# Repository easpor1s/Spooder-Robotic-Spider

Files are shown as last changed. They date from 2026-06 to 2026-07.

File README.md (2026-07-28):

Spooder Zine (1)

## What is Spooder?
The first iteration of Spooder is a remote controlled robotic spider companion with 6 legs. It has a led display that projects a face and facial expressions based on the actions it takes. 
At its core, the robot is powered by a 2gb Raspberry Pi 4 connected to a Pimoroni Yukon developement board through UART. The legs use a three jointed, two axis design which allows for a high degree of movement.
On the legs, one servo controls the legs movement along the X axis and two along the Z axis. This design is very similar to the joint of your finger and allows the robot to grab at objects and sweep itself along smoothly.



## How do I interact with Spooder?
The first iteration of Spider will be controlled via a game console controller such as an Xbox gamepad. The left joystick will control the robots front and back movement, while the right joystick will control the robots left and right movement. The controller will be 
connected to the robot via a 2.4ghz dongle, which keeps hardware requirements simple and reduces our costs. Using a controller with a dongle also eliminates Bluetooth pairing problems, which can be frustrating to troubleshoot. 
Additional functions will be mapped to the controller's shoulder buttons, directional pad, and the ABYX buttons as they are developed. The controller we are using is a 8BitDo Ultimate 2C game pad which has good buld quality and is very affordable. Spooder requires python 3.9 or newer, PIGPIO for controlling servos, and pygame. 

## Why does it exist?
Both of us are in the same robotics competition and wanted to try something new. We only built wheeled drivetrains for our Vex bots and any variation in design is still centered around wheels but just in different configurations. 
We decided to try something new, so we settled on a walker robot idea that relies on legs with servos instead of wheels with motors. Additionally, with our previous robots, the building and design experience was highly procedural where all the parts came from a standardized catalogue which made the experience feel repetitive. 
This project is our attempt at widening our hardware knowledge base and learning new skills while yielding something meaningful. Both of us have little to no experience with the components and steps we are using in the making of Spooder which is a steep learning curve and why this project is being attempted. 

## What are the future plans of Spooder?
In the future, we aim to have Spooder have the hardware to run a local large language model and be able to track and follow you without human input. 
We also aim for Spooder to be able to react to gestures such as waves, thumbs up, and maybe even give high-fives where it will raise on of its legs to tap your hand. In the future, components that will allow the bot to jump up onto or over obstacles may be added through spring or pneumatic systems as well. 

## Instructions
Because the models and enclosure is split into multiple components, assembly can be quite tricky.
- 3d print all models with petg or CF-petg except for the leg tips, which should use TPU.
- Add appropriate brass inserts and bearings, which should be heat set and friction fit appropriately
- Sand down joints if needed
- Assemble left and right legs, and mount the body servo arm to the top part of the legs
- Attach the motors to the mounts on the body, and then attach the leg assembly to them.
- Add electronics to the baseplate, and the LED matrix to the top enclosure
- Wire all components and add power supply and power bank
- Assemble all components together, the leg mounts, guards and top enclosure to the baseplate
## Setting up code
To set up code, first make sure all hardware dependencies are met. You will need a Pimoroni Yukon with 5 servo modules attached, a USB-A to USB-C cable running from the Raspberry Pi to the Yukon, a gamepad dongle plugged into the pi and your gyro connected to the pi through i2c as well. On the software side, you must have Python 3.9 and the Pigpio system on the Pi. 

PowerShell:

powershell 
```sh
-ExecutionPolicy Bypass -File .\deploy.ps1 -PiHost "your_pi_ip" -PiUser "your username"
```
Raspi Terminal:

Setup Environment:
```sh
ssh your_username@your_pi_ip_here cd /home/your_username/hexapod chmod +x setup_pi.sh ./setup_pi.sh 
```
Install sys dependancies:
```sh
sudo apt-get update
sudo apt-get install python3 python3-pip python3-venv pigpio python3-pigpio git -y
sudo systemctl enable --now pigpiod
```
Install Libraries:
```sh
cd /home/your_username/hexapod source venv/bin/activate pip install --upgrade pip setuptools wheel pip install pygame pyyaml pip install --no-cache-dir adafruit-circuitpython-lsm6ds 
```
Run controller: 
```sh
sudo /home/your_username/hexapod/venv/bin/python3 /home/spooder/hexapod/main.py 
```

## Built With
[PIGPIO](https://github.com/joan2937/pigpio) for servo control

[pygame](https://github.com/pygame/pygame)

## Programs
[Autodesk Fusion](https://www.autodesk.com/uk/products/fusion-360/overview) for CAD design

[Canva](https://www.canva.com/) for graphic design

[CirkitDesigner](https://app.cirkitdesigner.com/project/475be11a-6594-4d5f-bd77-2635c9dc39ba) circuit diagram

[Desmos](https://www.desmos.com/) movement calculations

[Visual Studio Code](https://code.visualstudio.com) Code and SSH access

## License
Distributed under the MIT License. See [MIT License](https://opensource.org/licenses/MIT) for more information.

## Circuit diagram
Spooder Wiring

## Inverse Kinematics Calculations
2d https://www.desmos.com/calculator/ezvpfhsskw
3d https://www.desmos.com/3d/tjnpyzfqji





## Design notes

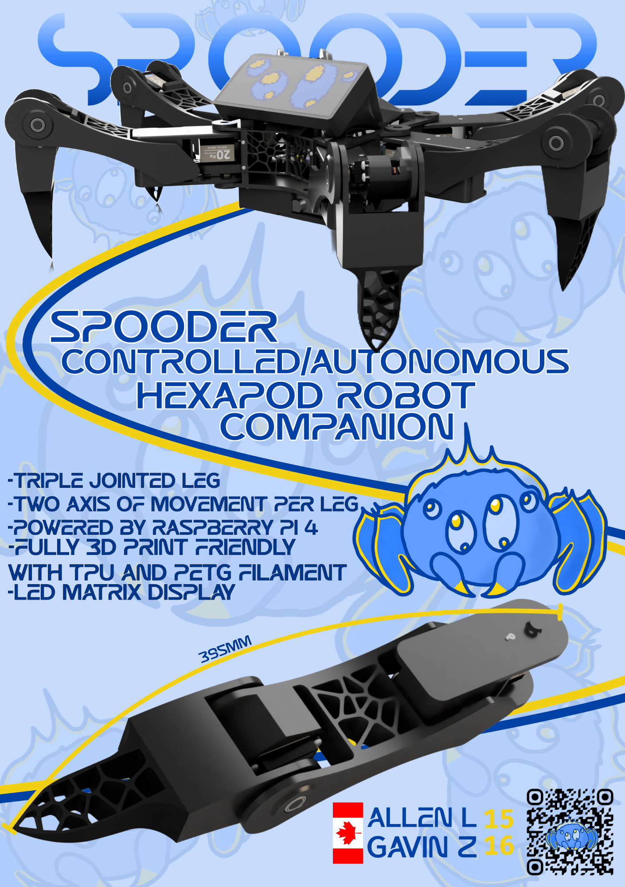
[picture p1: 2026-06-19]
Spooder Zine.png

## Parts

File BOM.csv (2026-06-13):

Component | Description | Quantity | Unit Cost in CAD | Total Cost in CAD | Source | Ownership
Pimoroni Yukon | Servo control board | 1x | $37.32 | $37.32 | https://shop.pimoroni.com/products/yukon?variant=41185258111059
Gyro & Accel | Gyro for stability | 1x | $19.11 | $19.11 | https://shop.pimoroni.com/products/adafruit-lsm6ds3tr-c-6-dof-accel-gyro-imu-stemma-qt-qwiic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
Servo Module | Adapter add servos to Yukon | 5x | $9.00 | $37.32 | https://shop.pimoroni.com/products/quad-servo-module-for-yukon?variant=41187321446483
Servo 4 pack | Servos | 4x | $65.00 | $259.96 | https://www.amazon.ca/HOOYIJ-Digital-Waterproof-DS3225-Steering/dp/B0D6RRGDLP
Servo 2 pack | Servos | 1x | $43.98 | $43.98 | https://www.amazon.ca/dp/B08DCHGRXG?ref=ppx_yo2ov_dt_b_fed_asin_title
T to XT30 adpt | Adpt to onnect LIPo to Yukon | 1x | $9.99 | $9.99 | https://www.amazon.ca/LinsyRC-T-Plug-Connector-Adapter-Battery/dp/B0CZTNMJHF
2S LIPo 2 pack | Batteries to power servos | 1x | $34.64 | $34.64 | https://www.amazon.ca/GOLDBAT-5200mAh-Connector-Airplane-Helicopter/dp/B08CV8TLFT
STEMMA cable | Connect gyro to pi | 1x | $2.81 | $2.81 | https://shop.pimoroni.com/products/jst-sh-cable-qwiic-stemma-qt-compatible?variant=40409136332883
2.5 Scrw 50pc | Assembly Screws | 1x | $9.98 | $9.98 | https://www.amazon.ca/M2-5-0-45x10mm-Phillips-Machine-Stainless-Countersunk/dp/B0FB8XR995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
2.5 Scrw btn 565 pc | Assembly Screws | 1x | $16.53 | $16.53 | https://www.amazon.ca/dp/B075RCLBBH?ref=ppx_yo2ov_dt_b_fed_asin_title
Bearings 30pc | Bearings | 1x | $22.31 | $22.31 | https://www.amazon.ca/Fafeicy-10x15x4mm-Shielded-Precision-Applications/dp/B0GK24M3W8
Brass insert 100pc | Brass inserts for screws | 1x | $10.99 | $10.99 | https://www.amazon.ca/HANGLIFE-Heat-Set-Threaded-Printing-Components/dp/B0CS6YVJYD
TPU filiment | Filiment to print parts | 1x | $22.99 | $22.99 | amazon.ca/dp/B0BBM6R5VM?ref=ppx_yo2ov_dt_b_fed_asin_title
PETG filiment | Filiment to print parts | 1x | $32.99 | $32.99 | amazon.ca/dp/B0DFCF582M?ref=ppx_yo2ov_dt_b_fed_asin_title
Game Pad | Controller for Spooder | 1x | $33.29 | $33.29 | https://www.amazon.ca/8Bitdo-Ultimate-Controller-Joysticks-Remappable/dp/B0D72TNXSC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 | OWNED
Buck Convert | Adapt powerbank to Pi | 1x | $20.99 | $20.99 | https://www.amazon.ca/dp/B093VB61Y6?ref=ppx_yo2ov_dt_b_fed_asin_title
Raspberry Pi 4 | Controls Spooder | 1x | $100.23 | $100.23 | https://www.amazon.ca/Raspberry-Model-2019-Quad-Bluetooth/dp/B07TD42S27?sbo=RZvfv%2F%2FHxDF%2BO5021pAnSA%3D%3D | OWNED
Ugreen 67w | Power Raspi 4 | 1x | $57.84 | $57.84 | https://www.walmart.com/ip/ugreen-65W-20000mAh-Portable-Power-Pack-with-1-USB-C-cable-1-USB-C-port-1-USB-A-port/17498716367 | OWNED
USB-C adapt | Adpt powerbank to buck convert | 1x | $15.00 | $15.00 | https://www.amazon.ca/CERRXIAN-USB-5-5mm-2-1mm-Replacement/dp/B0DLKSWKN7
LED matrix | Display for Spooder | 1x | $39.15 | $39.15 | https://www.amazon.ca/Waveshare-Full-Color-Adjustable-Brightness-Compatible/dp/B0BQYDLHY9?s=electronics
8-32 inserts 50 pack | Threaded inserts for screws | 1x | $10.69 | $10.69 | https://www.amazon.ca/Threaded-American-Standard-Hardware-Components/dp/B0DS653YLX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
Matrix Bonnet | Connect screen to Raspi | 1x | $17.43 | $17.43 | https://shop.pimoroni.com/products/adafruit-triple-led-matrix-bonnet-for-raspberry-pi-for-hub75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
M3 screws | Assembly Screws | 1x | $13.59 | $13.59 | https://www.amazon.ca/M3-0-5-Button-Stainless-Machine-Threaded/dp/B0C6WLLV3H?sp_csd=d2lkZ2V0TmFtZT1zcF9hdGY
8-32 Screws 100 pack | Assembly Screws | 1x | $17.00 | $17.00 | https://www.amazon.ca/NIULUNBAO-Stainless-Machine-Threaded-Assortment/dp/B0DMV2WB4X?gad_source=1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
Total |  |  |  | $886.13
Total with Tax |  |  |  | $930.44

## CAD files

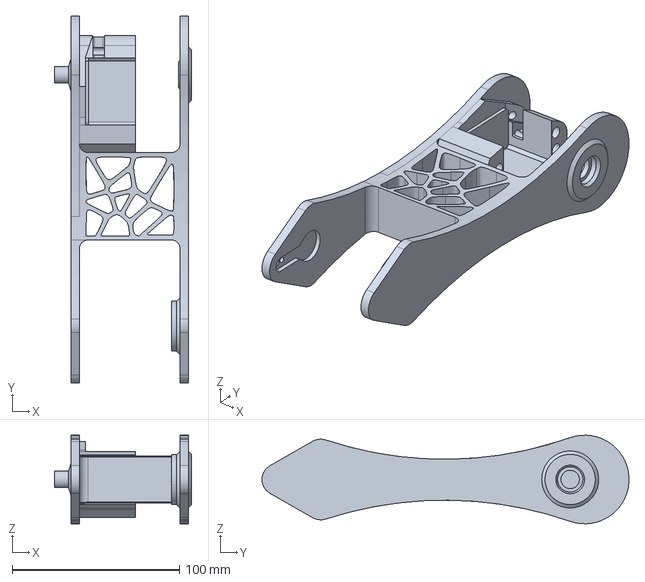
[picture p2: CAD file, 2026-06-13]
CAD/SpooderV1models/left_leg/left_mid.step
82.0 x 219.1 x 52.9 mm

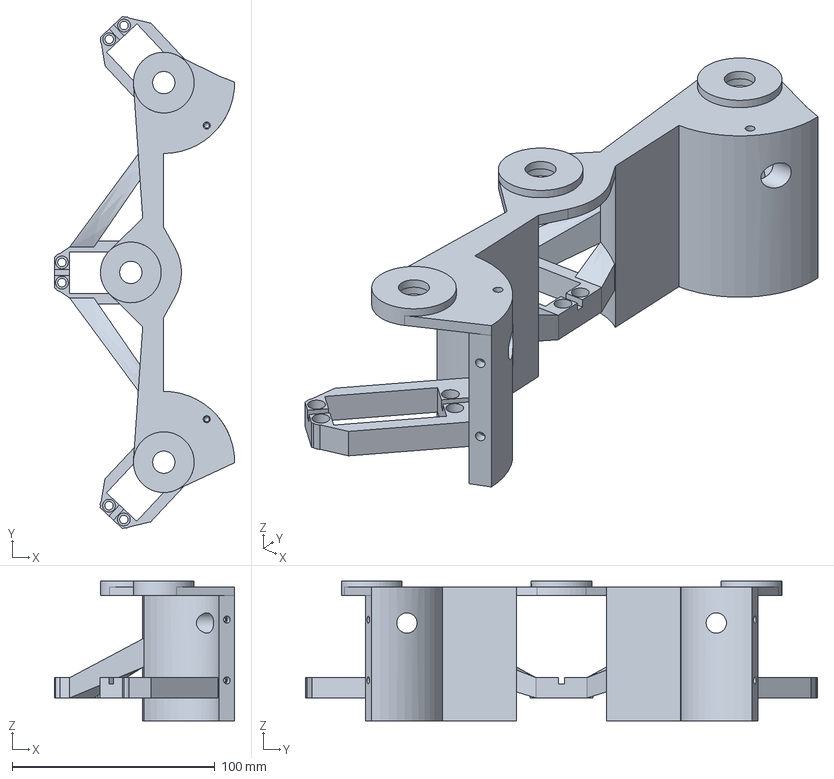
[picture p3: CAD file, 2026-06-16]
CAD/SpooderV1models/left_mount.step
89.0 x 252.8 x 69.0 mm

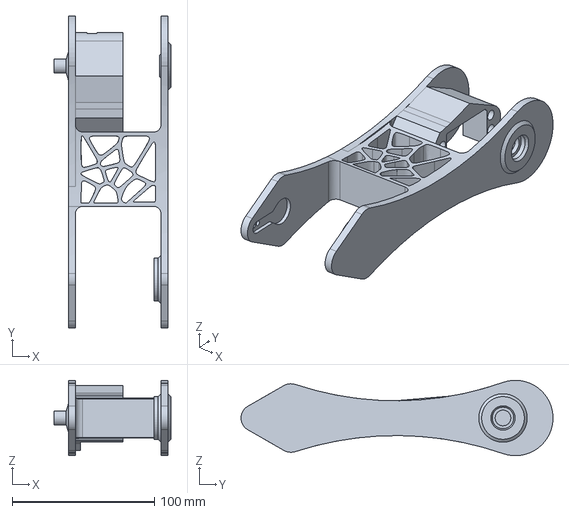
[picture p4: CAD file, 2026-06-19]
CAD/SpooderV1models/right_leg/right_mid.step
82.0 x 219.1 x 52.9 mm

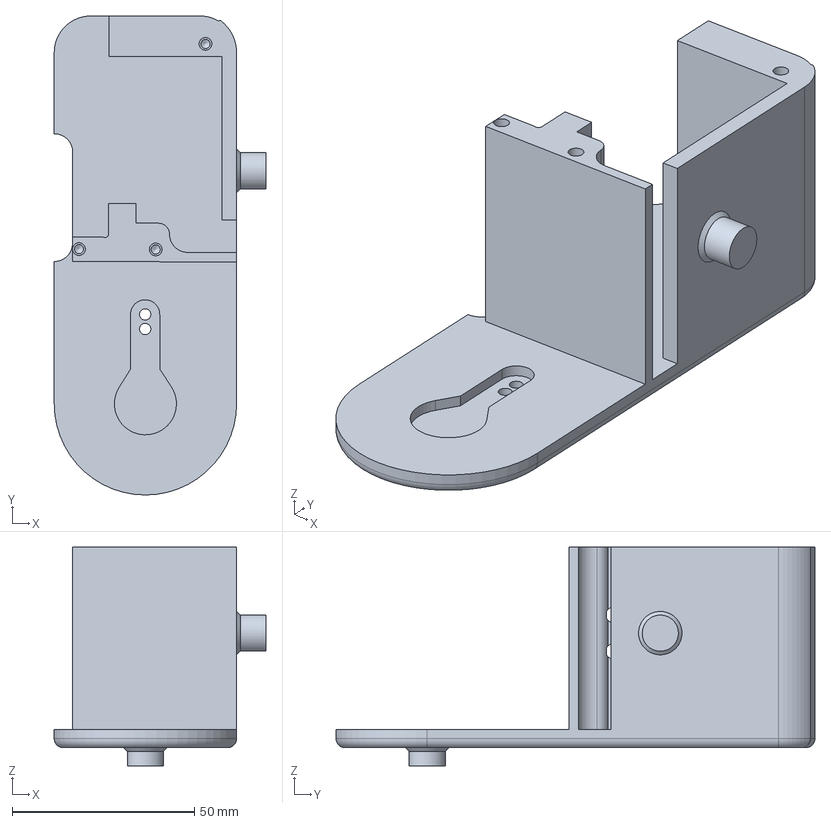
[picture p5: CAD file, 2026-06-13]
CAD/SpooderV1models/left_leg/left_upper_bottom.step
58.0 x 131.3 x 60.0 mm

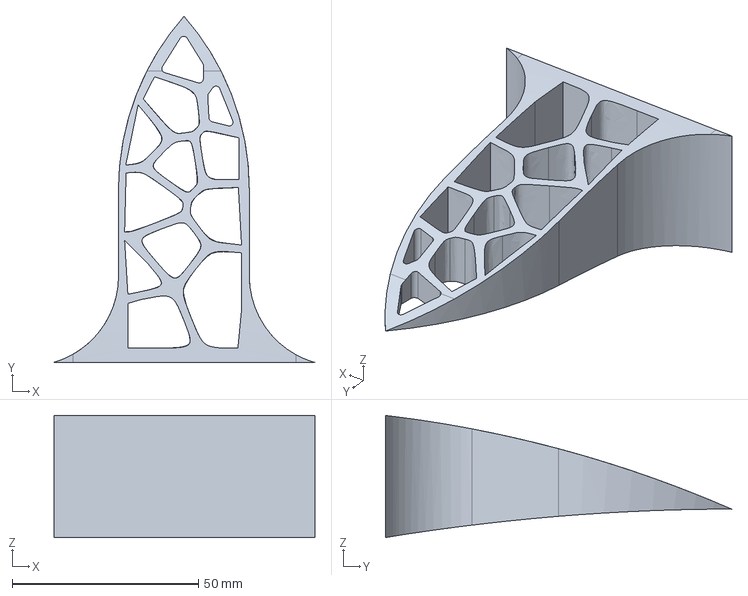
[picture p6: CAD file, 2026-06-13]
CAD/SpooderV1models/right_leg/right_claw_bottom.step
70.0 x 92.9 x 32.8 mm

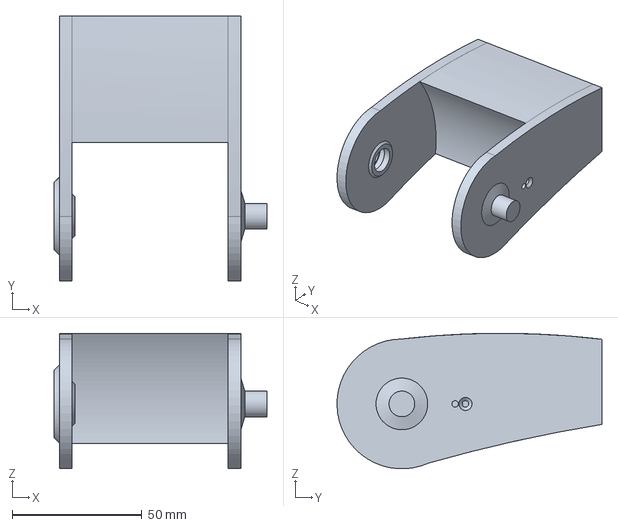
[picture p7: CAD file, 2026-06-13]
CAD/SpooderV1models/left_leg/left_claw_top.step
82.0 x 102.1 x 52.2 mm

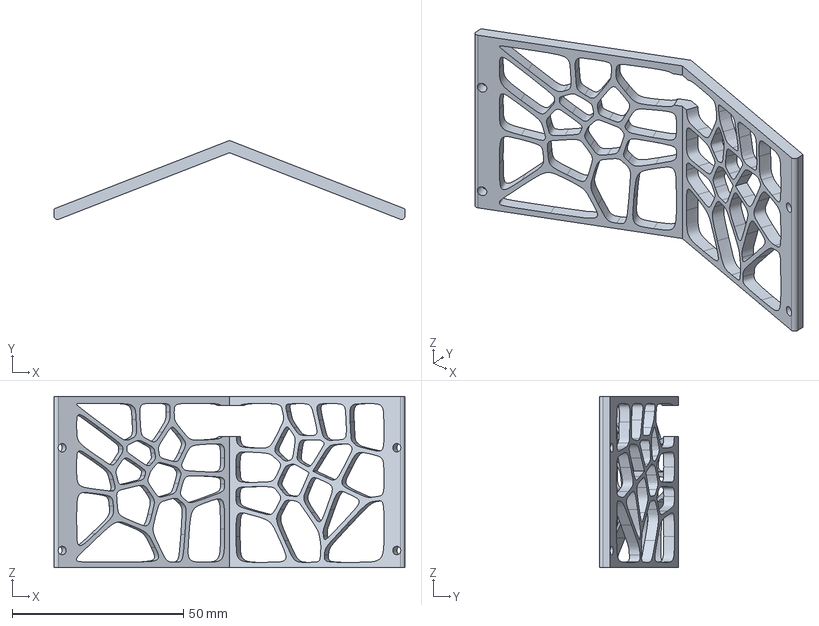
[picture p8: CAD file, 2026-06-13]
CAD/SpooderV1models/rearfront_guard.step
102.5 x 23.1 x 50.0 mm

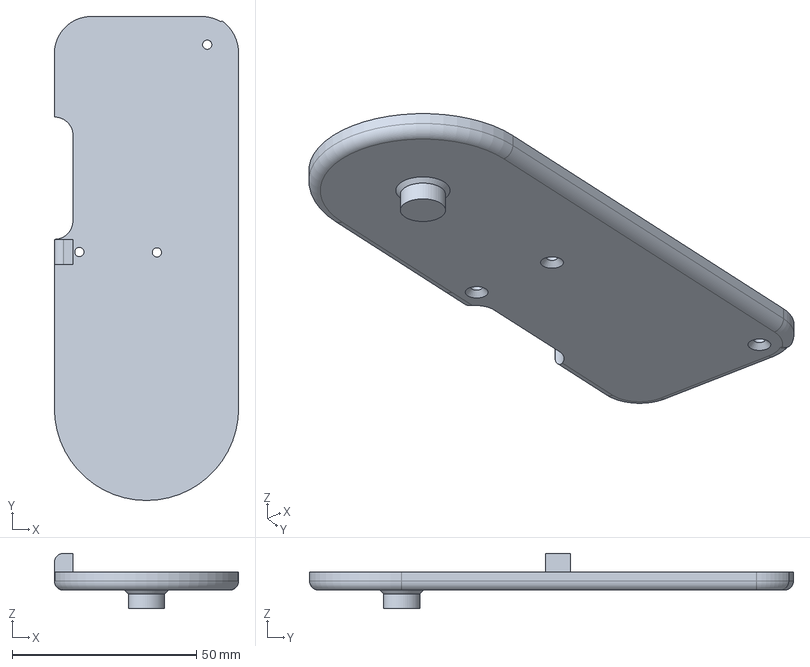
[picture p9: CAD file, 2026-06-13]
CAD/SpooderV1models/right_leg/right_upper_top.step
50.0 x 131.3 x 15.0 mm

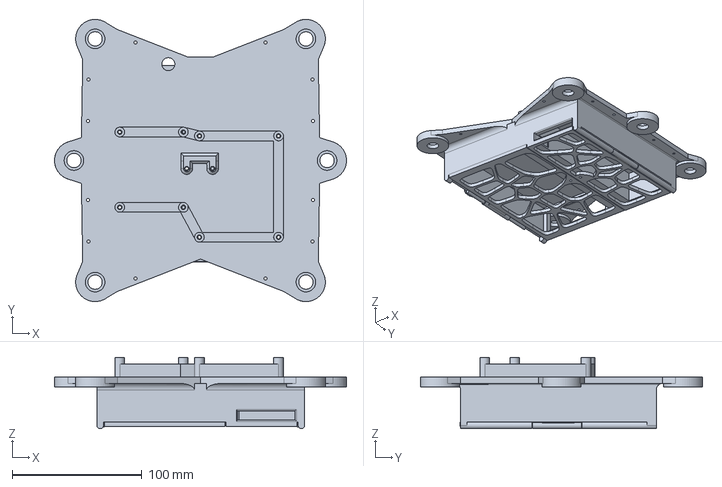
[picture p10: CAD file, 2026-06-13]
CAD/SpooderV1models/base_hinge.step
225.0 x 217.4 x 55.0 mm

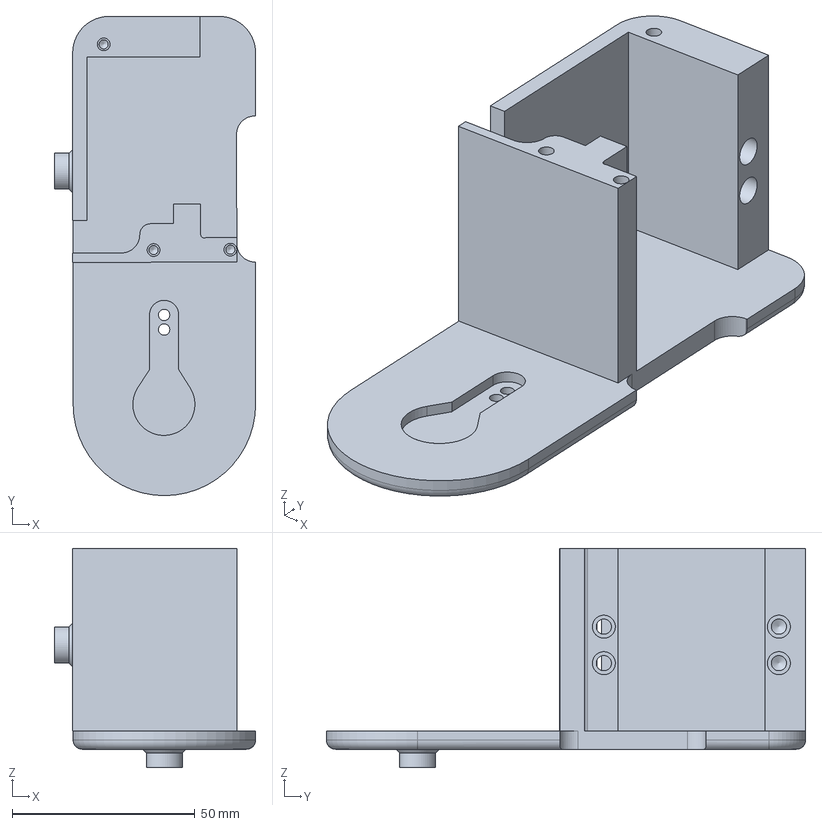
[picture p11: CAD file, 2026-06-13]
CAD/SpooderV1models/right_leg/right_upper_bottom.step
55.1 x 131.3 x 60.0 mm

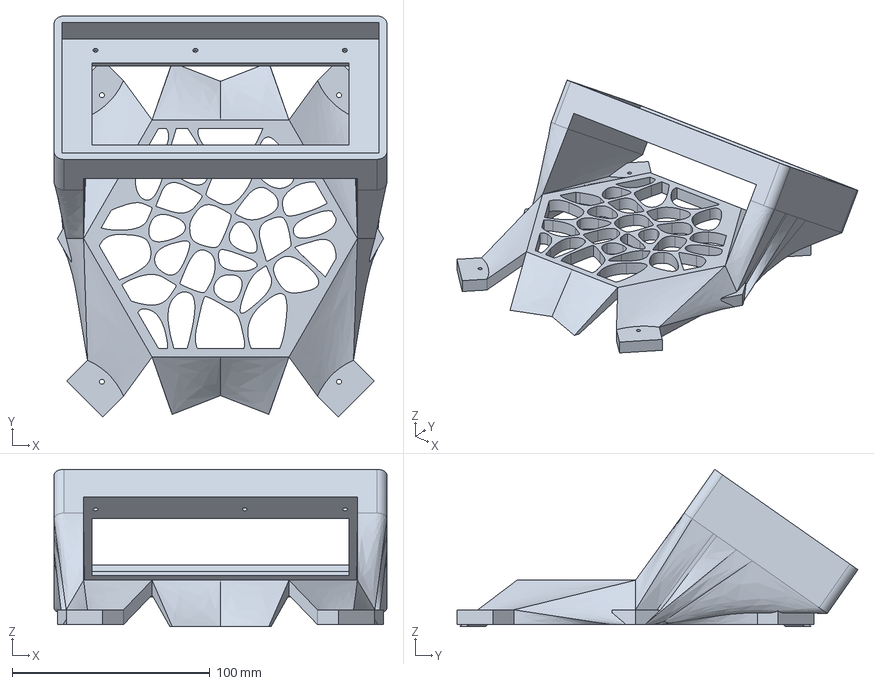
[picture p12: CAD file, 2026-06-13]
CAD/SpooderV1models/top_enclosure.step
168.5 x 202.9 x 79.6 mm

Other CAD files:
CAD/SpooderV1models/right_mount.step
CAD/SpooderV1models/left_leg/left_claw_bottom.step
CAD/SpooderV1models/left_leg/left_upper_top.step
CAD/SpooderV1models/right_leg/right_claw_top.step
CAD/left.f3z
CAD/right.f3z

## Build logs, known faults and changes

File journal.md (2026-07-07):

# Spooder — Journal Export

- Exported at: 2026-07-07T22:23:32Z
- Project ID: 4099
- Entries: 36

## Entry 1
- ID: 10595
- Author: allenlin0728
- Created At: 2026-05-31T05:44:50Z

### Content

I started by looking at an old prototype of one of the arms that i made a while back and kind of just taking in the design, but ended up deleting most of it. I started to research about herringbone gears, as we were going to 3d print some of them for our design, and pulleys/belt, which I was not very experienced with. From this I did a little bit of scouting of parts and created a very rough draft on FUSION of our arm, with the pulleys, herringbone gears and the servo motors. The belts/pulleys were the main focus, where I decided for a 300mm long GT2 9mm pulley/belt from my research.




### Recording Links

- https://www.youtube.com/watch?v=wEREaV_vIaY

## Entry 2
- ID: 10819
- Author: allenlin0728
- Created At: 2026-06-01T03:55:55Z

### Content

I started to polish my old design up, where i spent lots of time joining and creating different parts, like the pulleys/helical gears. But after discussing, Gavin and I decided to scrap the old design entirely after seeing some other designs of a similar robot, where we now decided to use 3 servos, and 6 legs to make the movement more refined smooth. This meant we had to scrap our old design, and create a new one. After learning the size of our servos, which was much lighter/smaller than expected, we decided on directly placing the servos onto the joints, with ball bearings for less friction. This now allows us to turn our legs individually, but requires much more servos.



### Recording Links

- https://www.youtube.com/watch?v=X4d5mncq7Mc
- https://www.youtube.com/watch?v=3uG8w2orfYI
- https://www.youtube.com/watch?v=HCluzsvRUsA

## Entry 3
- ID: 10820
- Author: deez.ducks.ca
- Created At: 2026-06-01T03:57:54Z

### Content

I researched and sorted all the electronic components and materials needed for the robot and added them to a spread sheet with individual and total costs. I created our Github and wrote the projects read me as well as uploading the cost and materials spread sheet onto it. I started the logo for the project zine and added it to the Github. Some other additional house keeping items have also been taken care of. I have also determined the basic work flow we are going to use to electronics such as which modules attach where, how is power stepped down and delivered etc. (started at 1:40 ended at 9:30, OBS wasnt working for a few hours and didnt realize)



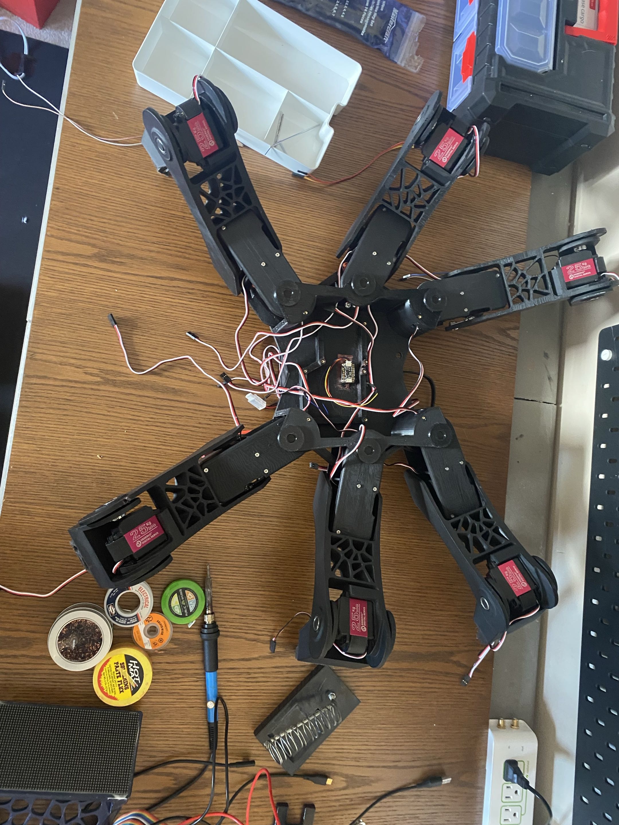
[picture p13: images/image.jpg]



### Recording Links

- https://www.youtube.com/watch?v=XxXYVmYsMW0
- https://www.youtube.com/watch?v=baPjPJVgMh8
- https://lookout.hackclub.com/api/media/7c6b96f3-029c-4d9d-af1d-7212b8e67b17/video.mp4

## Entry 4
- ID: 11060
- Author: deez.ducks.ca
- Created At: 2026-06-02T04:23:40Z

### Content

Polished GitHub, added milestone target and fixed some formatting issues. Researched and compiled electronics -> soldering iron, servos. Solved the major problem of how to power the Raspberry Pi 5 mobile on the robot at a reasonable cost. -> 67W Ugreen power bank with a USB-PD 2.0/3.0 to 5V 5A converter board. Researched and planned additional mounting hardware components to be used. Made a basic circuit diagram on how the electronics will be wired together. 


### Recording Links

- https://lookout.hackclub.com/api/media/a696c47c-5837-4988-a421-9487be0b5eb6/video.mp4

## Entry 5
- ID: 11065
- Author: allenlin0728
- Created At: 2026-06-02T04:42:57Z

### Content

I touched up the leg assembly by adding a pair of knobs as a axle fit for the ball bearings. 


After this I started on the main design, which would used 6 of these leg assemblies, but after moving some of the legs to the alternate side and flipping them around and rotating, I realized I had to mirror the other leg for a right side and a left side to have the motors oriented correctly. So I copied and edited one the leg assembly, flipping the top motor, which when rotated in the main assembly would allow for an alternate or mirrored leg. 


left side


right side

From this I positioned the legs temporarily at a even increment for simplicity.


One thing I noticed though is that the curve of the claw of the spider also needed to be mirrored, and possibly the central joint motors



I decided to do this tomorrow as it was getting that but this is to keep note of it.

### Recording Links

- https://www.youtube.com/watch?v=mTfh1b1T4Z4

## Entry 6
- ID: 11283
- Author: deez.ducks.ca
- Created At: 2026-06-03T02:57:15Z

### Content

Today I made a polished wiring diagram that was an enourmous improvement upon the previous one. This layout includes all the hardware that will be required for the robot to operate. This wiring diagram would allow us to assemble the robot more quickly and more efficiently, as it serves as an instruction sheet for the assembly of the electronics. Additionally, I determined that a Pimoroni Yukon would be a more suitable dev for our robot as it natively supports a direct connection to 2S LIPo and its hot-swappable servo modules. 
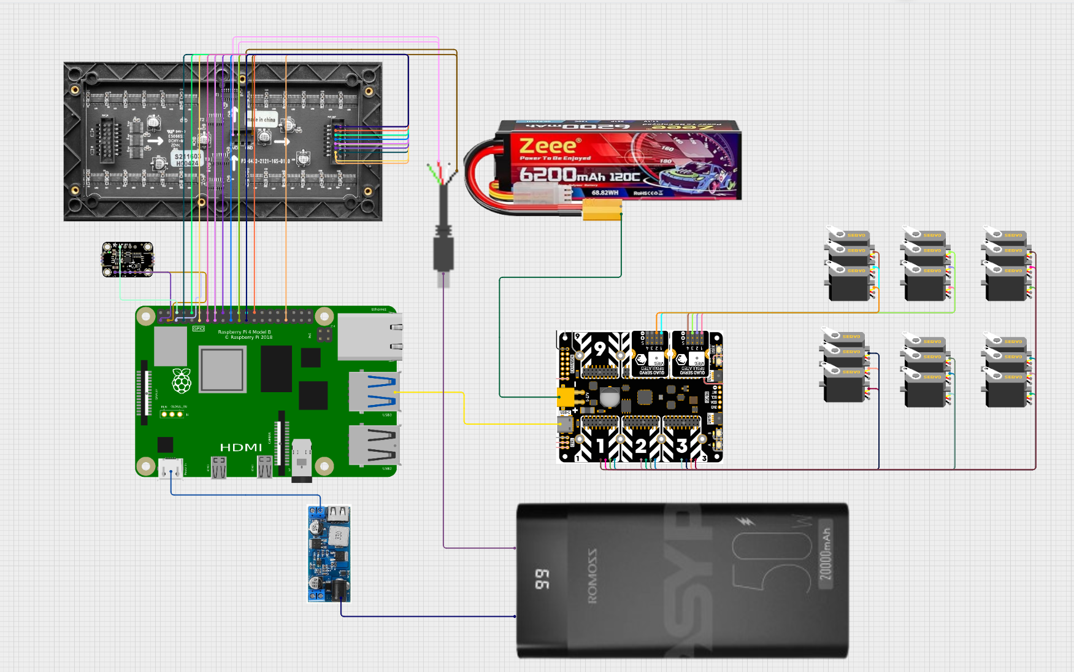
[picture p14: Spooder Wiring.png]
spooder wiring.PNG


### Recording Links

- https://www.youtube.com/watch?v=EKXB0rfb_ZY

## Entry 7
- ID: 11302
- Author: allenlin0728
- Created At: 2026-06-03T04:34:55Z

### Content

I decided to start by fixing some of the errors that came up when I was trying to combine some of the bodies for the joints of the legs. This required me to move a lot of sketches around and reestablish new profile planes. I also split the end of the legs where it comes to a singular point in half, where I could now 3d print the main part of the piece with a regular plastic and create TPU tips that I could glue on for traction. But because I only edited one of the legs to fix the errors and modify it, I decided to scrap the old left leg, and to just copy the right leg and to flip the components I needed, which was the direction of the point on the end of the leg and the body motor direction. I also downloaded files for bearings and then added them in to both sides.


right side


left side

### Recording Links

- https://www.youtube.com/watch?v=9oQujQrA6ts

## Entry 8
- ID: 11546
- Author: deez.ducks.ca
- Created At: 2026-06-04T05:10:30Z

### Content

I completely overhauled the bill of materials and was able to reduce the cost from $777 to $553, and I expect to be able to further reduce it later on. Most of the electronics, how they work, and how they integrate together are completely new to me, so I am learning as I go. I determined that a Pimoroni Yukon with 5 servo modules would serve our purpose the best, as it has a built-in LiPo battery connector. This board also allows us to scrap the Raspberry Pi and a separate servo board altogether, which makes assembly much simpler and also removes the need for a step-down converter for a servo board. This saves a ton of time and money. Additionally, I found that DS 3225 servos are much better suited for the project than the DS 3218 servos we were originally planning to use, as it provides a faster rotation speed and increased torque at the same price as the DS 3218 servos. 


### Recording Links

- https://www.youtube.com/watch?v=buhjz0CnnKA

## Entry 9
- ID: 11548
- Author: allenlin0728
- Created At: 2026-06-04T05:39:51Z

### Content

I downloaded the cad files for the brass heat set inserts that were used. For the m2.5 screws, I chose countersunk flat head screws because I wanted the minimal profile as this was necessary for the attaching the servos to the components while making the assembly as thin as possible. For the m4 screws, because these were primarily for mounting the body of the servos, I used regular button head screws for a smaller profile and no need for countersinking. One problem I encountered while trying to add these screws and inserts was that the mounting screws for the servo arm were very close together, meaning I couldn't use two screws regularly to mount it.



I resolved this by putting a button head screw on the other side so the screw heads would not interfere with each other.



This is the assembly with all the screws, bearings and inserts:




### Recording Links

- https://lookout.hackclub.com/api/media/c91c6fc0-5f60-4c47-87cc-74efcbfb8cee/video.mp4
- https://lookout.hackclub.com/api/media/f14bfdbd-4bc3-429a-b641-7cb3baa93ea6/video.mp4

## Entry 10
- ID: 11777
- Author: deez.ducks.ca
- Created At: 2026-06-05T05:18:36Z

### Content

The circuit diagram has been redone as we found a Raspberry Pi 4 in storage. This enables us to run more complex code and add new features. A major pain point previously was that the Pimoroni Yukon did not have any USB Type-A ports, which meant connecting a 2.4GHZ game pad would have been extremely difficult, but with the Pi, it has the required ports. Additionally, this allows us to use an 8BITDO  controller, which is known to work with the Pi but has absolutely no documentation with the Yukon. 
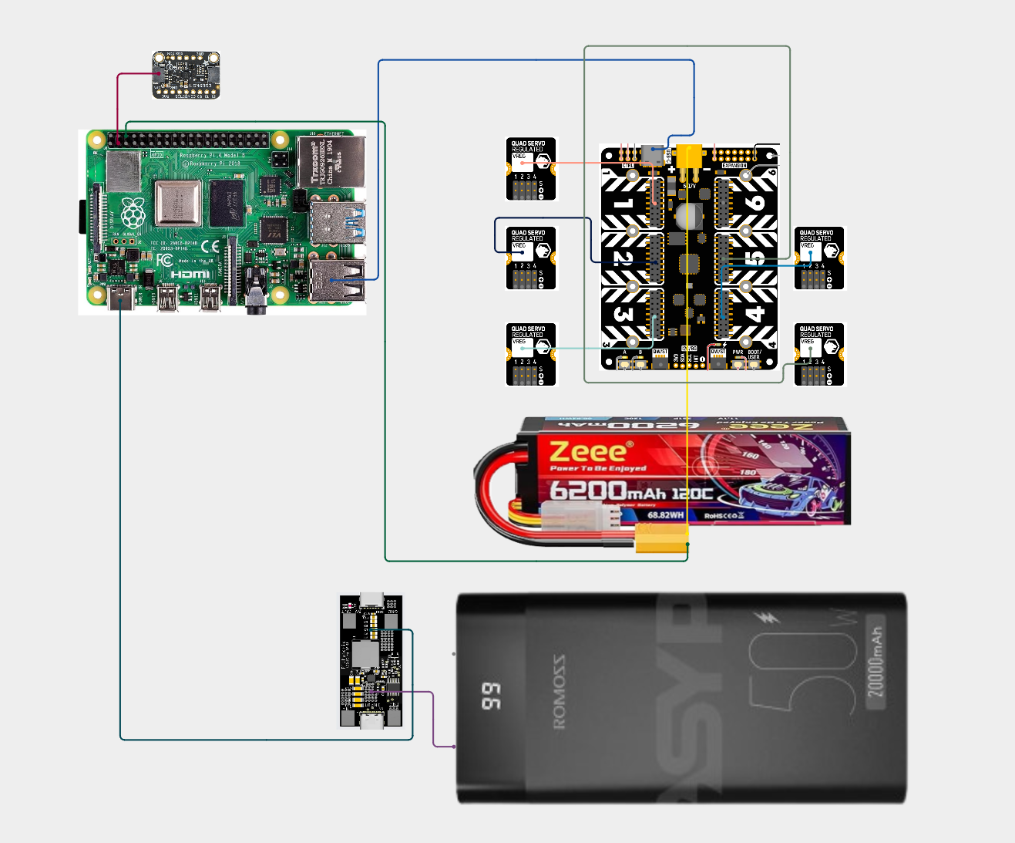
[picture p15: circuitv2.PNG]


### Recording Links

- https://lookout.hackclub.com/api/media/511be3ef-2075-4422-8def-bac8b7580443/video.mp4

## Entry 11
- ID: 11778
- Author: allenlin0728
- Created At: 2026-06-05T05:36:59Z

### Content

I finalized the legs, doing the last adjustments such as creating the right leg with the new components. With this I set up the legs in their correct orientation, and started to find the cad files for the other electronics as a guideline to start creating the body. 



### Recording Links

- https://lookout.hackclub.com/api/media/ef52723f-4624-44a8-849a-aead316a4be1/video.mp4

## Entry 12
- ID: 11988
- Author: allenlin0728
- Created At: 2026-06-06T04:10:28Z

### Content

Today I started to create the main body of the spider. I started by taking and finding the cad files of the electronics such as the Raspberry Pi 4, the IMU, the Pimoroni Yukon, and the batteries and creating a structure/layout for them. I decided the layout to involve having the power bank and the battery to be at the bottom for hotswapping, and the main electronics on the upper section of the body. I also ensured that the IMU was positioned in the exact center of the body for precision. 
Screenshot 2026-06-05 180103.png
Screenshot 2026-06-05 180126.png

With this I started to experiment with the positioning of the legs, at first I decided to put the legs relatively far away from the center, but that made 3d printing the body difficult, and unnecessary weight. From this I moved them so they would intersect the rectangular body, creating a hexagon star like shape, with just enough space for the body and legs. 

I now added the base plate, and positioned the Raspberry Pi and Yukon side by side, elevated up with standoffs, allowing the IMU to be positioned in the middle right under.


### Recording Links

- https://lookout.hackclub.com/api/media/f43f4d79-c17d-47ea-8be7-41a8878a5e98/video.mp4
- https://lookout.hackclub.com/api/media/da010aa7-f9f8-481b-81c4-ef146afcb895/video.mp4

## Entry 13
- ID: 11993
- Author: deez.ducks.ca
- Created At: 2026-06-06T04:41:19Z

### Content

I researched libraries and dependencies required for controlling the robot as we have never attempted a servo controlled walker bot before. I determined that PIGPIO is the best software for us as it avoids servo jitter which would be a catastrophic error for our robot. We did some brainstorming together and determined the next steps and course of action for implementing code and the positioning of Spooder's legs. On the hardware end, I managed to get the Raspberry Pi 4 working as it previously had a corrupt image and updated the Bluetooth and Python packages. Troubleshooting the Pi was the biggest challenge today as I have had no experience with single board computers before hand so I was learning as I went. I found the Raspberry Pi OS Lite was the optimal operating system for us as it saves the limited RAM we have on the pi and allows us to run heavier software. I also attempted to connect an older Xbox one gamepad that we had in storage but to no result as the controller already had a pairing issue. 


### Recording Links

- https://lookout.hackclub.com/api/media/ff5005c6-b4b4-4ba0-ab0b-f69e94fd0625/video.mp4

## Entry 14
- ID: 12212
- Author: allenlin0728
- Created At: 2026-06-07T05:58:29Z

### Content

Today I started to add the top section of the main body, where the top bearings are housed. But I noticed that a lot of the sketch lengths were different for some reason, so I assumed something about the main shape of the body was irregular, so I decided to redo it.



This new design was a little simpler than the previous, and was sligthly smaller, which meant that I had less room for error and slightly lower weight. From this, I started the top section of the housing, which would be composed of pillars coming from the bottom section.



I added a top cover with the loft function for structure

### Recording Links

- https://lookout.hackclub.com/api/media/b4c09e7a-00df-4e57-a936-9556db4edfdf/video.mp4
- https://lookout.hackclub.com/api/media/550bc495-696c-4d6f-b2fa-a5c7497e75ea/video.mp4

## Entry 15
- ID: 12425
- Author: deez.ducks.ca
- Created At: 2026-06-08T04:09:31Z

### Content

An issue I ran into today was getting file transfer using VScode SSH to function which is how we plan to transfer files from a computer to the Raspi. This issue is still unresolved. I started to code the control software for our robot  but only got very basic main control, calibration, and readme finished as we do not have the required hardware. I started on our Zine page and sketched out the spider character that is Spooder. 
Untitled 6.PNG

### Recording Links

- https://www.youtube.com/watch?v=PIIL-6kyG3A
- https://www.youtube.com/watch?v=Ju4qd_anXFk
- https://lookout.hackclub.com/api/media/97aa1a68-50c6-4adb-942d-2ef4f511fbfe/video.mp4

## Entry 16
- ID: 12429
- Author: allenlin0728
- Created At: 2026-06-08T04:57:04Z

### Content

I started by finishing up the bulk of my design, finalizing the enclosure and fixing some of the little details on it. I also added the mount for the power sources, which were the power bank and the battery, which would rest on the bottom of the robot. 


I also experimented with a screen I found on adafruit, which could be mounted and used to display different things in the future, and I cadded a mount for it.

However, when I started to export the files and prepare them for 3d printing, I realized that my 3d printer was too small for the main body. 
spooder v17.png
Screenshot 2026-06-07 161750.png
This meant that I had to redo the shape of the main body, moving the legs closer apart so the body would be less long. A lot of the sketches were messed up, which meant that I had to also re-extrude a lot of the shapes. Although this was a great set back, it also allowed me to fix one of the problems, which was the accessibility of the body, where a large body as one piece would mean that building would be very difficult/impossible in some places. I solved this by using a top enclosure and a bottom enclosure, mounted together with screws instead of one solid body, which would allow me to access the inside of the robot with ease, and be able to close it afterwards with a casing.  The cad is still unfinished, as i still have to figure out a lot of the wiring and accessibility, and the mount for the display.

### Recording Links

- https://lookout.hackclub.com/api/media/d9fe82c6-1c84-4215-8441-8b2910a375dc/video.mp4

## Entry 17
- ID: 12690
- Author: deez.ducks.ca
- Created At: 2026-06-09T05:34:50Z

### Content

Today I started on the first iteration of our zine page. I used a typeface that matches the character that we believe our robot represents, and chose a colour palette for the Zine page and any future designs related to our bot. For tomorrow, I want to find a way to implement a wireframe diagram of our robot on the zine page, as I really enjoy the aesthetic it adds. 


### Recording Links

- https://lookout.hackclub.com/api/media/19ec2be8-a3d6-4b82-a01d-a47af3ede811/video.mp4

## Entry 18
- ID: 12697
- Author: allenlin0728
- Created At: 2026-06-09T06:28:06Z

### Content

Today's work was to refine the core design of the spider that I currently had. I started by trying to track the size of the main body, which was now two pieces, but because of the new mounts for the servos that stuck out of the body, it was still too large for my 3d printer. This meant I needed another method to actually manufacture this with a reasonably sized printer. I opted for splitting the body into more pieces, where now it was now mostly 3 layers: the bottom mount, where all the controllers and the battery pack was mounted, the middle section which was comprised of a left and right section, which held the mounts for the servos and the bearings, and the top casing, which would have the display and also the top enclosure. All of these parts would be mounted together with screws, and is now fully 3d printable on my K1C, or a print bed of 220x220x235. From this I also bent the legs in a more natural way, where before only the last joint would be bent for convenience, but would not be accurate and would look a little weird, and now I would raise the first joint up and the second joint down, making a more natural leg joint that would be replicated in the project IRL. This came with lots of difficulty. At first I tried to edit all my leg files to have them bent correctly, however, this didn't do anything to my actual assembly's legs. Importing the new legs one by one and replacing them would also not work, as I had a sketch that relied on the old legs, and replacing them would mess all of that up. This meant that I had to manually edit all the joints, which would be very time consuming and would mean I had to select a ton of components, but in the end, I got it to work, making it visually accurate for the zine and github.

One of my timelapses from yesterday was seemingly deleted after I accidentally refreshed the lookout page but now it appeared again so i will be submitting that as well.


### Recording Links

- https://lookout.hackclub.com/api/media/d386b9d8-1e53-4be7-89a4-fa2b9229bcb9/video.mp4
- https://lookout.hackclub.com/api/media/46fa690c-a89c-46a9-80ad-902d3cf75ac6/video.mp4
- https://lookout.hackclub.com/api/media/51d6e1c4-6383-41f8-bef2-23e75b9a81f8/video.mp4

## Entry 19
- ID: 12945
- Author: deez.ducks.ca
- Created At: 2026-06-10T05:51:10Z

### Content

I revised the BOM and fixed some broken links. I finalized the Zine for the project and will only need to make some subheading text more legible tomorrow. 
zine png.png

### Recording Links

- https://lookout.hackclub.com/api/media/d43bfa0b-9c79-496c-bc32-51420e5aaa2e/video.mp4

## Entry 20
- ID: 12946
- Author: allenlin0728
- Created At: 2026-06-10T05:54:25Z

### Content

Today I added side guards for the body, which would prevent parts from falling out, although not very much contribution structurally. To save filament, I holed it out with a Voronoi diagram pattern that I used  for a lot of other areas, which would add style while being functional and relatively strong. 


I also created the screen mount, which would be an external part/assembly of components, for organization, and mounted it to the main body, using the loft function to attach it to the top enclosure. I also had to create a hole in one of the side plates for the display cable to go through.



Now the design is done to my knowledge, but is still missing some parts like screws and inserts for a full assembly. 


### Recording Links

- https://lookout.hackclub.com/api/media/7319f4cf-a0c6-4533-8021-827456508346/video.mp4

## Entry 21
- ID: 13127
- Author: deez.ducks.ca
- Created At: 2026-06-11T02:21:11Z

### Content

Today I finished the zine and added it to GitHub. I added all the parts required to build the robot to the BOM, including parts that we already own and updated the GitHub with it. I updated the GitHub README to get up to speed with the latest iteration of Spooders' design as well. 


### Recording Links

- https://lookout.hackclub.com/api/media/c188af03-4207-4d36-ae28-f73ba242787d/video.mp4

## Entry 22
- ID: 13171
- Author: allenlin0728
- Created At: 2026-06-11T05:59:12Z

### Content

Today I started to assemble the whole design, adding the proper screws, inserts and bearings to the correct places. I then created a spreadsheet with the data for a small pieces, which I would then use to update the BOM. 



I also figured out the original display I used, which was an adafruit 5inch tft display which required a seperate board that costed over 50 dollar CAD could be replaced with an led matrix, which has more suitable dimensions, and could be connected without a seperated board, and had a lower cost in general. 



edit: my computer crashed midway but when i thought it was fine the time lapse turned completely dark for some reason?

### Recording Links

- https://lookout.hackclub.com/api/media/d54fbae7-8229-49e7-b803-13778409952f/video.mp4

## Entry 23
- ID: 13374
- Author: deez.ducks.ca
- Created At: 2026-06-12T04:01:59Z

### Content

Today I finalized as well as organized the repository and revised the Zine to reflect some new material choices. We started printing a few small test components to make sure they will fit together properly. Today I also resolved the issue where we could not sent files to the raspberry pi due to a public key error and successfully connected our controller to the pi and made sure it will always work immediately.  


### Recording Links

- https://lookout.hackclub.com/api/media/c46fa32e-8cfc-46e6-ad01-4b6a717d9616/video.mp4

## Entry 24
- ID: 13382
- Author: allenlin0728
- Created At: 2026-06-12T05:11:29Z

### Content

Today I started the mount for the led matrix, which was 32x64 with a 2.5mm pitch. However I couldn't find any official cad files or datasheets for it with the mounting holes, but luckily I found an old post with all the measurements for the mounting points.



I then used this to edit my old "screen" mount cad to fit the new LED matrix, and then added it to my assembly with my other components for the screen. I had some difficulty connecting it to the top enclosure, but i managed to make it work with the loft function and splitting the back of the matrix mount with a sketch. 

This is the fully assembled cad for now


I did run into a problem though, which was with wiring of the matrix and the IMU. Because the matrix used most of the GPIO ports including the I2C pins, it could not be used with the IMU, which needed those ports. This could be solved with a led matrix bonnet, which would be attached directly on top of the pi and connecting to the matrix, but still leaving the I2C pins open. Once I figured this out, I fully updated the BOM, which would now include everything needed, and was now formatted in a better way for a CSV file. Before the BOM had hyperlinks, but after exporting to csv i realized it didn't actually export the links and exported the titles of the links, so I changed them all to regular links and pushed it to the github.

I also started to export the F3Z file to the github, which was the complete cad of the assembly, however the file size was too large for the web version of github, which made me use the desktop version for the first time in a while.

I also exported all the 3d models for 3d printing, and added them into a folder for the github. In addition, I also laid out all the files and models on my slicing software, and thankfully, all of the models fit nicely.



From this I decided to start 3d printing the first test run of the leg, which would allow me to see if the assembly would work or not, in a cheap PLA filament I had beforehand.

Now most of the design is done, leaving only an update to the zine, which used my old cad render, and the wiring diagram, which needed to be finished.

### Recording Links

- https://lookout.hackclub.com/api/media/6072bd65-821b-409f-b922-38a30c82cbac/video.mp4
- https://lookout.hackclub.com/api/media/63f370cc-74c3-43dd-b58c-266aacffe299/video.mp4
- https://lookout.hackclub.com/api/media/7554433f-f54f-429d-bfc5-9048ff405e09/video.mp4

## Entry 25
- ID: 13533
- Author: deez.ducks.ca
- Created At: 2026-06-12T19:18:15Z

### Content

Properly formatted BOM and added description and owned materials. Created new and updated wiring diagram so assembly will be smoother, 
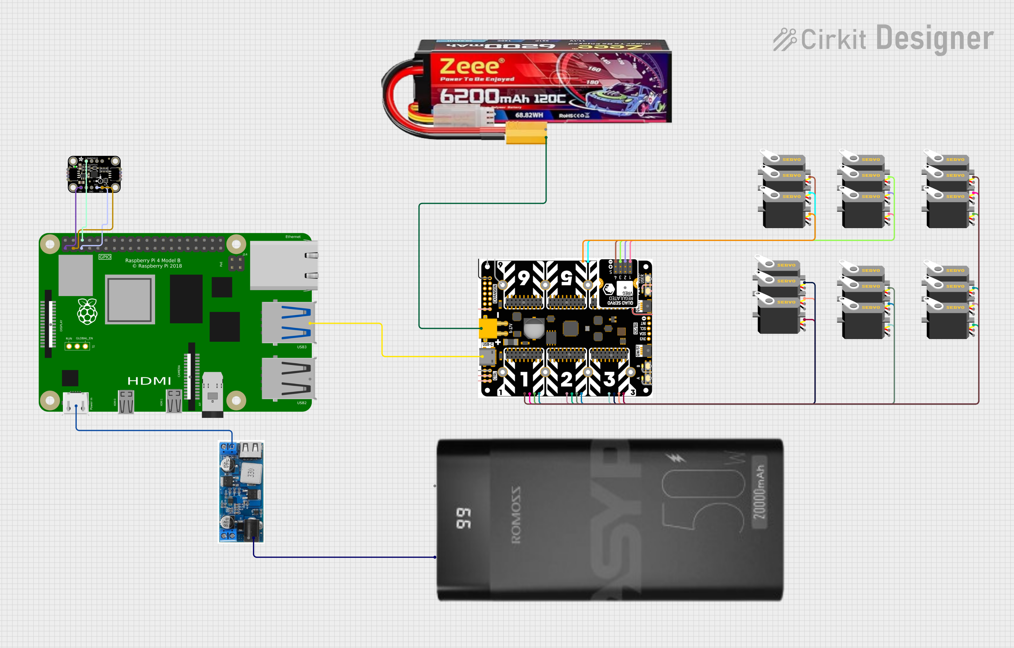
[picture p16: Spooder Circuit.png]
Spooder Circuit.png


### Recording Links

- https://lookout.hackclub.com/api/media/af99b3c3-6794-4603-a782-1103430dc81a/video.mp4

## Entry 26
- ID: 13645
- Author: allenlin0728
- Created At: 2026-06-13T05:24:53Z

### Content

After 3d printing the components for the legs I removed the supports and assembled it, although not with a loose fit because of the lack of bearings. However, I realized one of the joints of the legs were being blocked by the mid section of the leg. So I shrunk the  size of the support in the middle for it, and now it should not hit the joint. I also started to 3d print the guards with CF petg, as it was the only other filament I had. I also revised the entire project for submission, and submitted it. 





### Recording Links

- https://lookout.hackclub.com/api/media/c280b416-2fd7-44b3-9af7-cf6f45cbb7c5/video.mp4

## Entry 27
- ID: 14159
- Author: allenlin0728
- Created At: 2026-06-15T03:40:19Z

### Content

After doing some testing with the prototype models that I had, and the servos which arrived, I realized that the servos could not be fitted inside the component, because the wire could not be routed with my current design. So I expanded the slit in the model where the wire could be routed from for ease. I also found out that the mounting for the servo arm should be using m3 screws, and not m2.5, so I redid those mounting holes in CAD. Luckily I had those types of screws lying around, so no extra cost was used.

Another thing I updated in my cad of the leg was the side of the leg housing, which would interfere with the movement of the servo arm. I solved this by adding a grove on the side, allowing the servo to be rotated all the way without interference. 


The last problem that I had to fix was the direction of tips of the legs, where even though the left leg's tpu tip should be good, it's mount for it is wrong, where it is facing a different direction. I fixed this by mirroring the direction of the sketches for the leg tips, which worked out well.


I also altered the BOM spreadsheet a little, as some of the components I bought were a little different from the ones in the previous BOM, so I added those all in to create a more accurate total. The total funds needed from grants is 692.81 CAD, or roughly 500 USD, which is enough from just the 120 hours that are required from the two of us.


When I finshed 3d printing the side mounts i noticed that i didn't actually cad in the inserts to mount the servos in, and when I tried drilling the insert holes out, it cracked. I figured that the actual part was fine, as I used the wrong settings on the drill making it unsuitable for 3d printed parts and a drill bit too large, and that just cadding the insert holes in would be enough.

I also started to test the LED matrix, which I assembled then hooked up to the power bank where we tested it with the raspberry pi 4. However, It only worked after following some code from a tutorial and rewiring it again, which took quite a lot of time. 

### Recording Links

- https://lookout.hackclub.com/api/media/a840cd48-fd43-4f39-bfd5-a03a2da39b51/video.mp4
- https://lookout.hackclub.com/api/media/d514cf1e-9ec1-4e62-805b-44f1d0b28694/video.mp4
- https://lookout.hackclub.com/api/media/3bfb2692-922d-4c74-a9e9-a1cfe7b15dbb/video.mp4
- https://lookout.hackclub.com/api/media/8df52cf9-b56a-46bf-bd01-bdfcf1cb86ea/video.mp4
- https://lookout.hackclub.com/api/media/f445703a-512a-4040-8e63-f5517fbdc1c7/video.mp4
- https://lookout.hackclub.com/api/media/96a985f8-62f1-476f-9a58-934dae39745b/video.mp4

## Entry 28
- ID: 14175
- Author: deez.ducks.ca
- Created At: 2026-06-15T05:34:35Z

### Content

Today I sanded and spray painted a few of the parts we have printed to cover up the layer lines and imperfections  of the 3d print. I also organized all the parts we have on hand into part organizers so building will be much smoother and we will not lose parts and have to replace them. We got the led matrix display working after a few hours as we encountered a few problems which includes wiring the display to the pi, finding a library that was compatible and actually getting a image to display on the matrix. We also spent a few hours fixing the 3d printer as the nozzle had gotten clogged with filament.  
Untitled 6 (1).PNG

### Recording Links

- https://www.youtube.com/watch?v=7pUh69Jf6yY
- https://www.youtube.com/watch?v=9hQ_gLS9bDk
- https://www.youtube.com/watch?v=U-3WffL-74A
- https://lookout.hackclub.com/api/media/abf4c82c-22f8-47bc-bdc7-16f762714b3a/video.mp4

## Entry 29
- ID: 14651
- Author: allenlin0728
- Created At: 2026-06-16T23:28:07Z

### Content

We decided to borrow our friend's 3d printer to help speed up the printing process, which was an Ender 3. However, it didn't work instantly, and needed some tweaking. I first installed Marlin, which was a modded control system for the Ender which would help adjust some of the settings because of the newer firmware and additional features. The bed level and the home z-offset were very wonky, so I tried to manually set that in the configuration file, however, it only messed up the print, where the nozzle would touch the print bed, so I decided to manually set the bed level. Then I took the bed plate out and then reseated the springs and screws, which would ensure that tuning the would be easier because it was more evenly elevated.. I then used the paper test to level the bed, and then started a test print with it, which would be the top enclosure. However it failed and had some stringing and adhesion problems, so the next print i decided to add glue and adjust the temperature settings, and as of now it is still going smoothly. My main 3d printer also had some issues, most notably with layer shifting. Every time I would try to print the parts for the legs overnight, the print would fail as the entire print would shift to the right a bit. 

I searched online for people with similar problems, and turns out the most likely problem was that the belt was tensioned too loose or tight. This meant I had to tune the belt to the recommended 110Hz at 15cm to prevent my prints from failing, which took a while but eventually was done by loosening 4 screws on the back side of the printer, and then setting their positions on a slide, tensioning/loosening the belts. 

I also pushed my changes to my cad on github

### Recording Links

- https://lookout.hackclub.com/api/media/75719a8c-83f6-49d2-87a4-16379e7794de/video.mp4
- https://lookout.hackclub.com/api/media/2273a4bd-e84a-4ccf-9c3a-51e4f85537a4/video.mp4
- https://lookout.hackclub.com/api/media/ab46b595-45a0-4d8a-9f7a-d62f5b2422a1/video.mp4
- https://lookout.hackclub.com/api/media/7cdb4498-41ce-45f9-bc27-405865001d4d/video.mp4
- https://lookout.hackclub.com/api/media/06e5fd0b-da9a-4f13-a17e-cf1d98a563ce/video.mp4

## Entry 30
- ID: 14937
- Author: allenlin0728
- Created At: 2026-06-18T05:32:57Z

### Content

After I printed some of the components of the legs and body,  I took of the supports and sanded them down, which prepared them for spray painting. However, while I was 3d printing something, A print ran out of filament, and I had to go change it. But I accidentally took too long letting the filament in the tube extrude out, which meant that the printer would print a empty layer or two, messing up the 3d print. I had not noticed until I ran the 3d printer for a long time noticing that one of the structures has collapsed. When I stopped the print and took the components out of the bed, only two of them were usuable, a very flat piece belonging to the top of the leg and the middle section, which could pr9obably be joined together with adhesive. I also figured out the cable length needed for the robot beforehand, which was around 400-425mm of jumper wire for the back servos on the arm. Since the servos already came with  300mm of wire, I only needed to solder together 6 male to female cables that are 125 mm long(for extra clearance) to the servos. I also tested out the mounting of the servos and bearings and it looked like it was all okay, with adequate tolerances for them to be friction fit. 



### Recording Links

- https://lookout.hackclub.com/api/media/23b38faa-dced-40ec-8d21-fe78adfaa621/video.mp4
- https://lookout.hackclub.com/api/media/e9a04edf-9360-4ffb-96d1-6823effe3fda/video.mp4
- https://lookout.hackclub.com/api/media/a16f32fb-6f98-45a6-83dd-bb6aa18a055e/video.mp4
- https://lookout.hackclub.com/api/media/fb4edfca-ad98-401a-9ffa-9cfecf041473/video.mp4
- https://lookout.hackclub.com/api/media/882be93b-fd71-4fc3-b075-13fab9b89a8e/video.mp4
- https://lookout.hackclub.com/api/media/1980050a-9735-4eca-bc87-a774db4d705e/video.mp4

## Entry 31
- ID: 15150
- Author: allenlin0728
- Created At: 2026-06-19T04:10:40Z

### Content

Today I sanded down a lot of the parts we had printed, mostly sections for the legs, and then applied putty/epoxy on some pieces to repair some of the damage from the supports. We were also able to acquire yet another 3d printer from a friend, a ender 3 v2, which I tuned for PETG and printed a benchy on it, which made it ready to print the side pieces for the body, speedy up our process. After a couple fails over these past few days, we only need to reprint 2 out of the 4 parts for the right legs, and 2 more right legs. 

I also noticed that in my cad, the motors were not all facing the right direction for the middle servo, so I changed it and updated my cad and renders for this. And since the renders were updated, I also updated the zine accordingly and uploaded it to the github.




### Recording Links

- https://lookout.hackclub.com/api/media/2c720929-5ad5-437b-963c-9c1faea2037e/video.mp4
- https://lookout.hackclub.com/api/media/18c133de-03a7-4662-a2c2-9ad3c9d5220c/video.mp4
- https://lookout.hackclub.com/api/media/1be21dd5-21bd-4458-9a8f-0fca8aea38fd/video.mp4
- https://lookout.hackclub.com/api/media/6f488001-4fc1-4413-b7e2-cb3f4943d39e/video.mp4
- https://lookout.hackclub.com/api/media/6caa4ac9-2af9-484b-bf46-cd65c5bcfd38/video.mp4

## Entry 32
- ID: 15340
- Author: deez.ducks.ca
- Created At: 2026-06-19T20:56:57Z

### Content

Since we have a large led matrix display for Spooder, we wanted to give it some personality by making a custom eye animation for it. I used pixilart with a 64x32 canvas size which matches the matrix's resolution and created a animated gif that matches the mascot on our zine page. Determining the optimal number of frames and how long they should be displayed was the biggest challenge when animating the screen. 


### Recording Links

- https://lookout.hackclub.com/api/media/0b8e2a46-d49e-4e92-9107-f11c86920189/video.mp4
- https://lookout.hackclub.com/api/media/b96c5770-71f3-4349-a9ca-ee0a16d9a599/video.mp4
- https://lookout.hackclub.com/api/media/db7271ce-7d50-4c3e-9272-f45229d745a3/video.mp4
- https://lookout.hackclub.com/api/media/c3e76322-9602-41d0-a08c-70915af5e929/video.mp4

## Entry 33
- ID: 15347
- Author: deez.ducks.ca
- Created At: 2026-06-19T21:18:44Z

### Content

One of our prints failed where the printer didn't extrude anything for a couple of layers which resulted in the print breaking in half when handling. I attempted to solve this by stitching the two pieces back together using leftover filament and a soldering iron to limited success. I was able to join the two pieces and the connection seemed strong, the tolerances for the bearings and the cut-outs for where the servos attach to the print could not be met so we decided to scrap it.  

I also spent some time putting in the heat set inserts for mounting servos and other printed components together with our soldering iron and  spray painted them afterwards. 

Many areas of our prints have large imperfections and holes where the printer made an error or where the supports were. Sanding these areas directly would cause the surface layer to degrade and expose the infill underneath which is highly undesirable. To solve this I used automotive spot putty to fill in the imperfections and after it dried, used a higher grit sandpaper to smooth it out. This yielded a very smooth surface that, when painted, gave the part a highly refined look. 


### Recording Links

- https://lookout.hackclub.com/api/media/3b8b7164-2a76-4053-926f-5bbc2091e8ba/video.mp4
- https://lookout.hackclub.com/api/media/2397f458-195c-4ea8-9657-39bbd3164a20/video.mp4
- https://lookout.hackclub.com/api/media/4965ca29-0d46-4bac-90db-4c9f62cf96e0/video.mp4
- https://lookout.hackclub.com/api/media/fbc3cd4b-f417-4df7-b979-d36ef12400fe/video.mp4
- https://lookout.hackclub.com/api/media/ab087cc3-2fae-4f78-bac4-37f97fce64fd/video.mp4
- https://lookout.hackclub.com/api/media/cf2f2279-3410-4a00-af0d-fff422575614/video.mp4

## Entry 34
- ID: 15361
- Author: deez.ducks.ca
- Created At: 2026-06-19T22:13:11Z

### Content

When I uploaded the custom Spooder eye gif to the screen, the background was red even though the gif was exported without a background. After doing some digging, I found that gifs do not store transparency the same way as png's do and the fix was to edit Pillow so it knew which pallet index is  transparent and set them to alpha 0. 


### Recording Links

- https://lookout.hackclub.com/api/media/fda90cc8-3685-4bc4-a655-473c78df6e93/video.mp4

## Entry 35
- ID: 16488
- Author: deez.ducks.ca
- Created At: 2026-07-07T14:33:01Z

### Content

Over a few days, I prepped, painted, and assembled the remainder of the legs of the robot and used contact cement to attach the TPU tips. Finally, the legs were attached to the body, and all the electronics were screwed in (Raspi and Yukon). The power bank and Lipo battery slide into hot-swap compartments. Also started making cable extensions for the servos, as the tip servos do not have long enough wires to reach Yukong. 


### Recording Links

- https://lookout.hackclub.com/api/media/c6fec259-a8a9-442b-bcab-046e55344bf6/video.mp4
- https://lookout.hackclub.com/api/media/6a40360b-ccac-4e77-ad23-e3782c60aa73/video.mp4
- https://lookout.hackclub.com/api/media/99a6f1e2-02b7-4650-ae23-26e295d018a6/video.mp4
- https://lookout.hackclub.com/api/media/e33b8bdb-7b92-4c37-a590-2ead18f9aaef/video.mp4
- https://lookout.hackclub.com/api/media/ec859c41-08bc-4fab-8728-b1e40288eaae/video.mp4
- https://lookout.hackclub.com/api/media/e0bb0c31-9192-46de-b6c3-85f784ed1e66/video.mp4
- https://lookout.hackclub.com/api/media/2ec8e805-f578-41e1-bdce-43b5beb95caf/video.mp4

## Entry 36
- ID: 16496
- Author: allenlin0728
- Created At: 2026-07-07T22:18:45Z

### Content

I sanded the new parts with 120 grit sandpaper to remove the highest print lines then moved between a mix of 320 and 400 grit sand paper to smoothen the surface for painting. I started to paint the parts with a coat of primer then matte black spray paint. I also assembled the Yukon by inserting the modules then securing them with screws. 
Screenshot 2026-07-07 at 4.17.50 PM.png

### Recording Links

- https://lookout.hackclub.com/api/media/4e8515e1-842b-4d1c-8b8c-6fe7d26ef205/video.mp4
- https://lookout.hackclub.com/api/media/a1696e64-6fbf-4f25-9dac-62863c450064/video.mp4
- https://lookout.hackclub.com/api/media/1479a85d-c049-4db0-b5f8-40c8ee7941f4/video.mp4
- https://lookout.hackclub.com/api/media/291ab643-83f8-4087-a142-0f69ab7c2d03/video.mp4
- https://lookout.hackclub.com/api/media/9ee2aa5e-ed7c-4284-9588-3aff21b494cf/video.mp4
- https://lookout.hackclub.com/api/media/24c21f8e-306b-40d8-a56c-e4ca537a8b21/video.mp4
- https://lookout.hackclub.com/api/media/f262a63f-6026-4694-ba4d-c68c1f35441e/video.mp4
- https://lookout.hackclub.com/api/media/bdbc4ba8-05f8-4c5f-89c9-5d6e9946e96c/video.mp4
- https://lookout.hackclub.com/api/media/4c8861d0-36d1-4c23-86df-299ad2247261/video.mp4
- https://lookout.hackclub.com/api/media/b365b17a-cef2-4f38-86b1-37bb57bdfe30/video.mp4
- https://lookout.hackclub.com/api/media/20054f1c-eac0-43a0-ba95-1c4292f5ecb4/video.mp4
- https://lookout.hackclub.com/api/media/beb38e6b-7d28-481d-8946-d6371c6a1be5/video.mp4
- https://lookout.hackclub.com/api/media/af407ec4-8793-4fea-99d5-d0ea7bcad82f/video.mp4

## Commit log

2026-06-01 Cost and materials sheet
    Added table with costs, materials, and total cost.
2026-06-02 Added cost of materials spreadsheet
2026-06-04 Added overhauled bill of materials
    [Spooder Parts.csv]
2026-06-04 Added new BOM
2026-06-05 Added Circuit Diagram
2026-06-05 Added Interactive Circuit
2026-06-05 Added crude circuit diagram
2026-06-07 Revise Raspberry Pi model and add libraries section
    Updated hardware specifications and added library information.
2026-06-11 Spooder version 1 complete CAD
2026-06-11 Right side leg CAD
2026-06-11 Left Site Leg CAD
2026-06-11 Left Side Leg CAD
2026-06-11 Bill of Materials
2026-06-12 add fusion files
    [left.f3z, right.f3z]
2026-06-12 Added total to BOM
    [BOM.csv]
2026-06-12 Spooder circuit diagram
2026-06-12 Spooder Bill of Materials
    [Spooder Parts.csv]
2026-06-12 added folders and new edited cad
    [left.f3z, right.f3z]
2026-06-13 Update README with assembly instructions and project details
    Added assembly instructions and clarified project goals.
2026-06-13 updated cad files
    [left.f3z, right.f3z]
2026-06-13 update cad again
    [base_hinge.step, left_claw_bottom.step, left_claw_top.step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]
2026-06-16 update cad
    [left_mount.step, right_mount.step]
2026-06-17 Rename Screenshot 2026-06-16 184512.png to wiring_diagram
2026-06-17 added circuit designer
2026-06-17 Enhance README with Spooder details and instructions
    Updated the README to include additional details about Spooder, including interaction methods, future plans, assembly instructions, and setup code.
2026-06-19 update right leg
    [right.f3z, right_mid.step]
2026-07-14 Update README with Spooder project details
    Added detailed project description, interaction instructions, assembly guidelines, and setup code for Spooder robotic spider.
2026-07-27 Enhance README with Spooder project details
    Updated the README to include additional details about Spooder, its functionality, interaction methods, assembly instructions, and software setup.
